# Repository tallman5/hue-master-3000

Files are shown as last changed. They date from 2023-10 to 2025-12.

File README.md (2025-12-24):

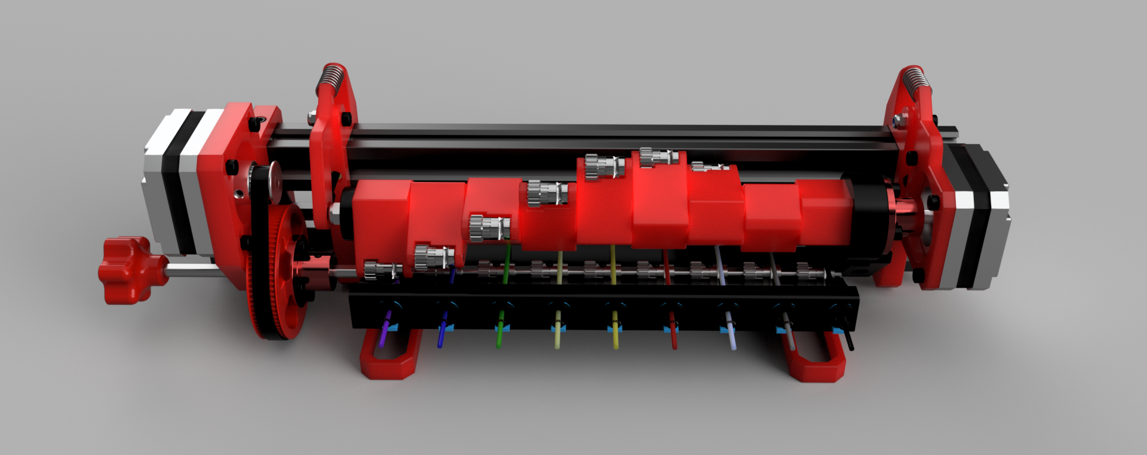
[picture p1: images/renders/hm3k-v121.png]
Hue Master 3000


# Hue Master 3000
The HM3K is a custom designed and built 3D printing MMU.

> [!WARNING]
> This project is still in Alpha phase. Use files at your own risk!

Watch the demo (https://youtu.be/Q2AsmqYf1VI)

BOM: [HM3K BOM](hm3k-bom.md)

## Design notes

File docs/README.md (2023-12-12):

# Assembly Instructions

## Printing the Parts
> [!WARNING]
> Failure to print the tests and callibrate the printer can lead to issues during assembly.

Before printing all the parts, print the test parts in the `../stl/test-prints` folder.
It's extremly important to ensure the printed parts fit together properly.
If they do not, the extrusion multiplier is probably what needs to be modified.

For reference, HM3K was built and tested with the following:
1. Print settings: Voron settings found in the [Voron Sourcing Guide](https://docs.vorondesign.com/sourcing.html) for all parts. The `feeder-block-9.stl` was printed with the infill dropped to 18%
1. Print profiles: Based on [AndrewEllis93's Profiles](https://github.com/AndrewEllis93/Ellis-SuperSlicer-Profiles)
1. Printer Tuning: [AndrewEllis93's Tuning Guide](https://ellis3dp.com/Print-Tuning-Guide/)

The two parts in the Voron Thread Test should screw together easily, not much force.
Once screwed together, there shouldn't be any wobble.

The HM3K test is a simple part which has holes for most of the critical joints used during assembly.
It has:
1. A tight hole in the side for a 6x3 mm magnet
1. A loose hole in the side for a 6x3 mm magnet
1. A hole down the center for testing the PTFE collet, clip, tube and filament
1. A hole to test a 5mm nut, should be snug but not difficult to instert the nut

## Next Step
1. Push extrusions through motor mounts, both directions

The HM3K is divided into two main assemblies, the Feeder (bottom) and the Selector (top).
They are joined with the two spine parts.

Next Step: [Feeder Assembly](./feeder-assembly.md)

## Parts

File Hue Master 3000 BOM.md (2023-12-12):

# Hue Master 3000 BOM
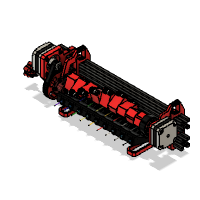
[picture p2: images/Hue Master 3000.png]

|Image|Name|Number|Description|Quantity|
|-|-|-|-|-|
||2020 V-Slot 300mm v2:1|2020 V-Slot 300mm||2|
||2GT 6mm Belt 5mm Shaft v3:1|HW1654WC|Affiliate Link: https://amzn.to/3tqusuo|1|
||Bearing MR85ZZ 5x8x2.5 v4:1|Bearing MR85ZZ 5x8x2.5|Affiliate Link: https://amzn.to/3LHrXdJ|1|
||Bowden Clip v5:1|Bowden Clip|Affiliate Link: https://amzn.to/3LXpI5Z|9|
||Bowden Collet v6:1|Bowden Collet|Affiliate Link: https://amzn.to/3LXpI5Z|9|
||Carrot Feeder Knob v2:1|Carrot Feeder Knob|Printed Part|1|
||Feeder Block v57:1|Feeder Block|Printed Part|1|
||Feeder Stepper Mount v34:1|Feeder Stepper Mount|Printed Part|1|
||Filament Gear Driven Assembly v5:1|Filament Gear Driven Assembly|Affiliate Link: https://amzn.to/3ZD1MdW|9|
||Filament Gear Idler Assembly v2:1|Filament Gear Idler Assembly|Affiliate Link: https://amzn.to/3ZD1MdW|9|
||Flange Coupling 5mm Assembly v4:1|Flange Coupling 5mm Assembly|Affiliate Link: https://amzn.to/46wvvrd|2|
||Foot v8:1|Foot||2|
||GT2 80T Wheel v8:1|GT2 80T Wheel|Printed Part|1|
||GT2 Belt 6x188 mm v2:1|GT2 Belt 6x188 mm|Affiliate Link: https://amzn.to/48znyTP|1|
||Hinged Spine v7:1|Hinged Spine||2|
||M3 Hex Lock Nut v1:1|HW1251NC||2|
||M3 T-Nut 2020 v2:1|HW1665NC|Affiliate Link: https://amzn.to/3RQrWbh|18|
||M3x10 SHCS v4:2|M3x10 SHCS|Affiliate Link: https://amzn.to/45f6QX4|9|
||M3x12 SHCS v3:1|M3x12 SHCS|Affiliate Link: https://amzn.to/3RQOZCR|2|
||M3x20 SHCS v2:1|M3x20 SHCS||1|
||M3x5x4 Threaded Insert v3:7|M3x5x4 Threaded Insert|Affiliate Link: https://amzn.to/48DnORF|10|
||M3x8 SHCS v3:1|M3x8 SHCS|Affiliate Link: https://amzn.to/3thA1vh|26|
||M5 D Shaft 269mm v3:1|M5 D Shaft 269mm||1|
||M5 Hex Lock Nut v2:1|HW1039NC|Affiliate Link: https://amzn.to/3RCXtxg|1|
||M5 Hex Nut v4:1|M5 Hex Nut||2|
||M5 Rod Threaded 205mm v1:1|M5 Rod Threaded 205mm||1|
||M5 Washer v3:2|M5 Washer|Affiliate Link: https://amzn.to/46Cpbyv|3|
||NEMA17 Square Short v5:1|NEMA17 Square Short|Affiliate Link: https://amzn.to/48Glbyz|2|
||Selector Arm v21:1|Selector Arm|Printed Part|9|
||Selector Axle End v12:1|Selector Axle End|Printed Part|1|
||Selector End Stop v15:1|Selector End Stop|Printed Part|1|
||Selector Flange Mount v26:1|Selector Flange Mount|Printed Part|1|
||Shaft Arm v13:1|Shaft Arm|Printed Part|1|
||Spring 20x8 Compressed v2:1|Spring 20x8 Compressed||2|
||Stepper Arm v12:1|Stepper Arm|Printed Part|1|

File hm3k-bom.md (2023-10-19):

# HM3K BOM


> [!WARNING]  
> This project is still in Alpha phase and the BOM is not complete. Use files at your own risk!

|Image|Name|Number|Description|Quantity|
|-|-|-|-|-|
||2020 V-Slot 260mm v1:1|2020 V-Slot 260mm||1|
||2020 x 250mm v1:1|2020 x 250mm||1|
||2GT 6mm Belt 5mm Shaft v3:1|HW1654WC|Affiliate Link: https://amzn.to/3tqusuo|1|
||Bearing MR85ZZ 5x8x2.5 v4:1|Bearing MR85ZZ 5x8x2.5|Affiliate Link: https://amzn.to/3LHrXdJ|2|
||Bowden Clip v5:1|Bowden Clip|Affiliate Link: https://amzn.to/3LXpI5Z|9|
||Bowden Collet v6:1|Bowden Collet|Affiliate Link: https://amzn.to/3LXpI5Z|9|
||Carrot Feeder Knob v2:1|Carrot Feeder Knob|Printed Part|1|
||Feeder Block v38:1|Feeder Block|Printed Part|9|
||Feeder Stepper Mount v20:1|Feeder Stepper Mount|Printed Part|1|
||Filament Gear Driven Assembly v5:1|Filament Gear Driven Assembly|Affiliate Link: https://amzn.to/3ZD1MdW|9|
||Filament Gear Idler Assembly v2:1|Filament Gear Idler Assembly|Affiliate Link: https://amzn.to/3ZD1MdW|9|
||Flange Coupling 5mm Assembly v4:1|Flange Coupling 5mm Assembly|Affiliate Link: https://amzn.to/46wvvrd|2|
||GT2 80T Wheel v8:1|GT2 80T Wheel|Printed Part|1|
||GT2 Belt 6x188 mm v2:1|GT2 Belt 6x188 mm|Affiliate Link: https://amzn.to/48znyTP|1|
||M3 T-Nut 2020 v2:1|HW1665NC|Affiliate Link: https://amzn.to/3RQrWbh|27|
||M3x10 SHCS v4:2|M3x10 SHCS|Affiliate Link: https://amzn.to/45f6QX4|9|
||M3x12 SHCS v3:1|M3x12 SHCS|Affiliate Link: https://amzn.to/3RQOZCR|9|
||M3x5x4 Threaded Insert v3:7|M3x5x4 Threaded Insert|Affiliate Link: https://amzn.to/48DnORF|8|
||M3x8 SHCS v3:1|M3x8 SHCS|Affiliate Link: https://amzn.to/3thA1vh|25|
||M5 D Shaft 269mm v3:1|M5 D Shaft 269mm||1|
||M5 Hex Lock Nut v2:1|HW1039NC|Affiliate Link: https://amzn.to/3RCXtxg|1|
||M5 Hex Nut v4:1|M5 Hex Nut||2|
||M5 Rod Threaded 205mm v1:1|M5 Rod Threaded 205mm||1|
||M5 Washer v3:2|M5 Washer|Affiliate Link: https://amzn.to/46Cpbyv|3|
||NEMA17 Square Short v5:1|NEMA17 Square Short|Affiliate Link: https://amzn.to/48Glbyz|2|
||Selector Arm v21:1|Selector Arm|Printed Part|9|
||Selector Axle End v12:1|Selector Axle End|Printed Part|1|
||Selector End Stop v10:1|Selector End Stop|Printed Part|1|
||Selector Flange Mount v26:1|Selector Flange Mount|Printed Part|1|
||Selector Motor Mount v18:1|Selector Motor Mount|Printed Part|1|
||Selector Shaft Mount v9:1|Selector Shaft Mount|Printed Part|1|
||Spine v6:1|Spine||2|

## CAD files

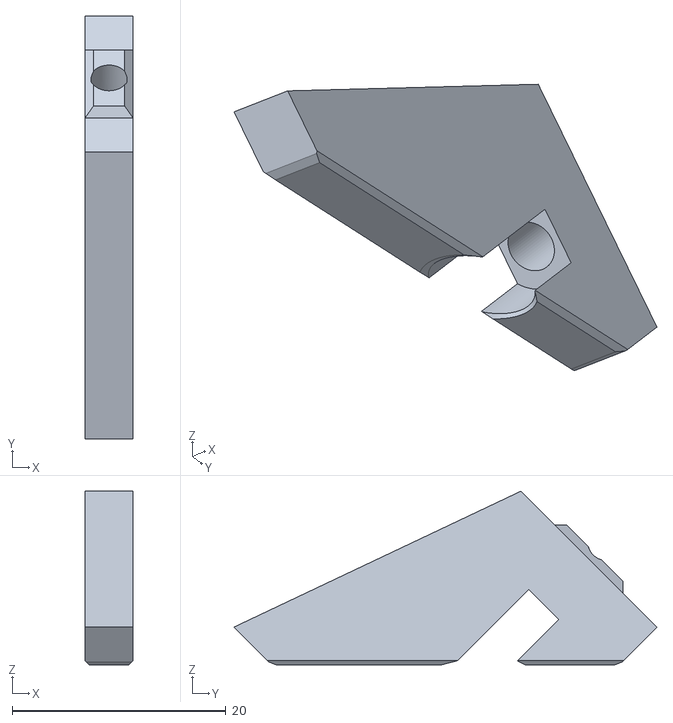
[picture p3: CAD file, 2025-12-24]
stl/ext-v-slot/selector-end-stop.stl
4.51 x 39.6 x 16.3

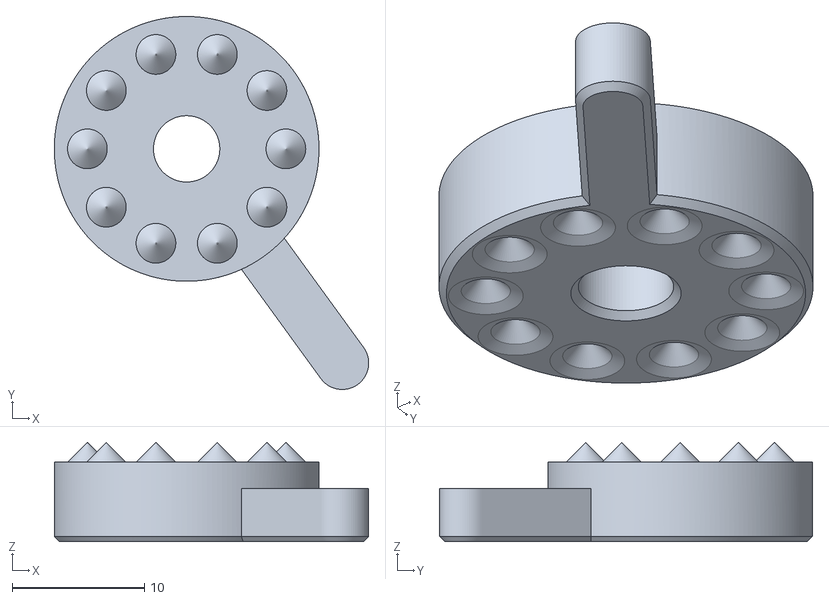
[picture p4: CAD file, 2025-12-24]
stl/selector-stop-arm.stl
23.8 x 28.2 x 7.50

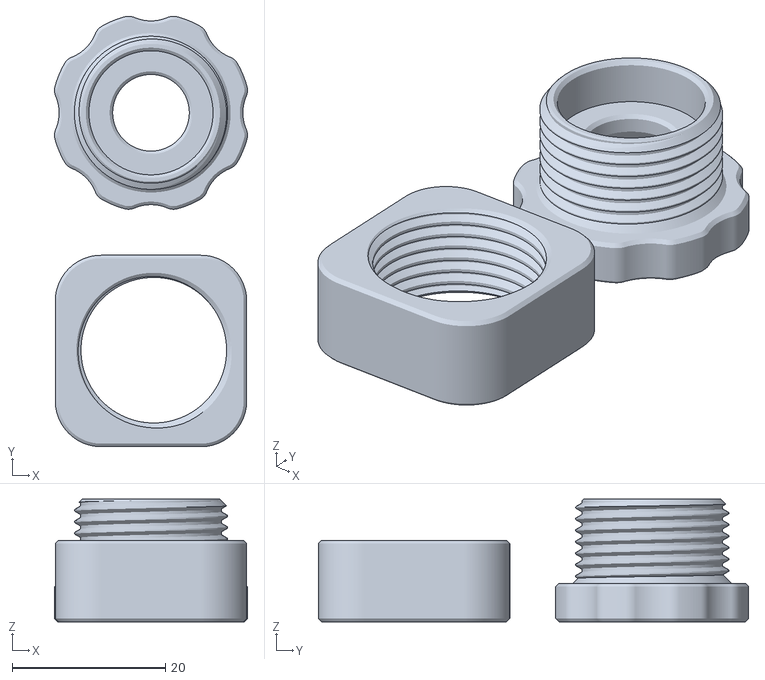
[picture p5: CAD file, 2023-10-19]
stl/test-prints/voron-thread-test.STL
25.2 x 56.2 x 16.0

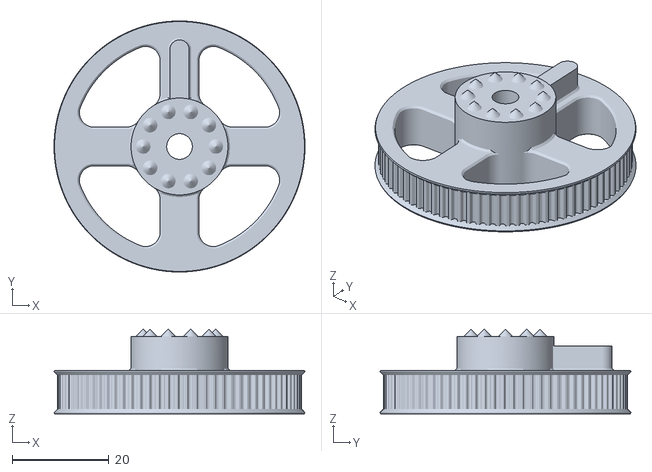
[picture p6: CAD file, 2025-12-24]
stl/[a]-selector-wheel.stl
51.8 x 51.8 x 17.5

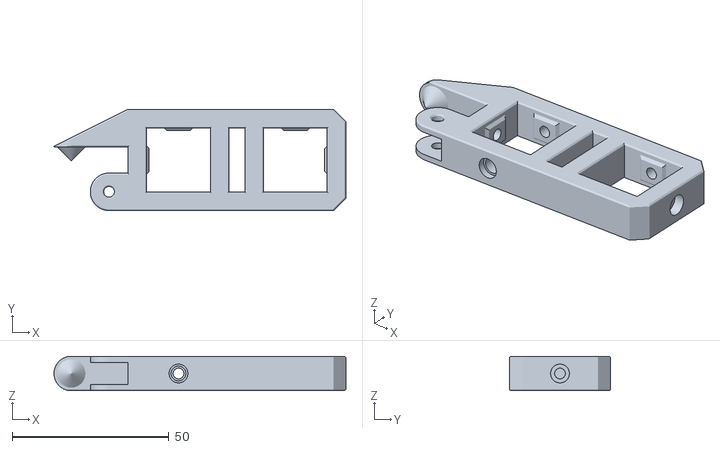
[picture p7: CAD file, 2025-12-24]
stl/ext-v-slot/hinged-spine-x2.stl
93.2 x 32.3 x 11.0

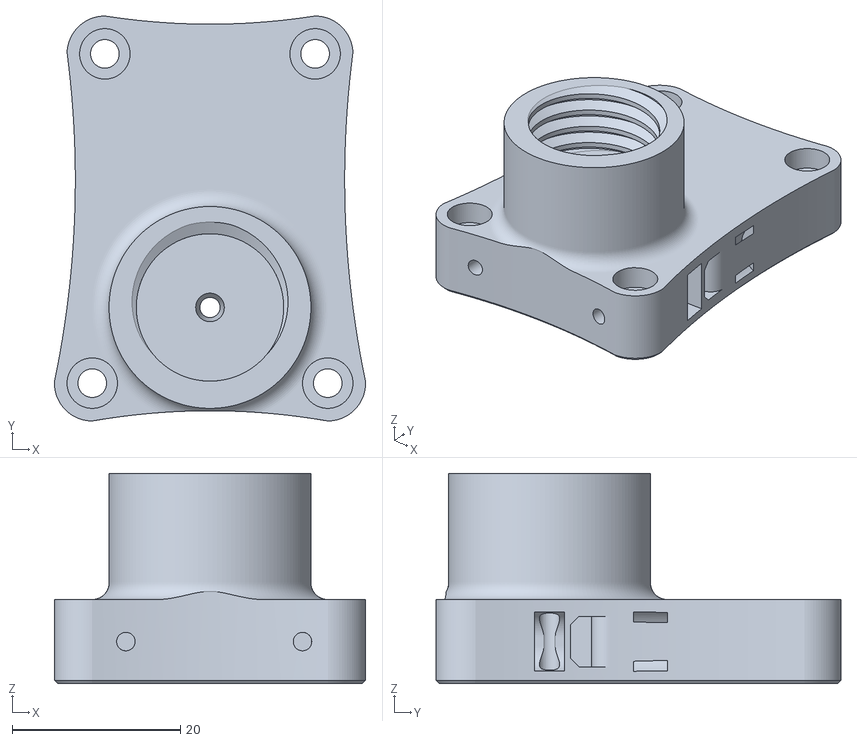
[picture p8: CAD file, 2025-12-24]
stl/ebm-mount.stl
37.0 x 48.2 x 25.0

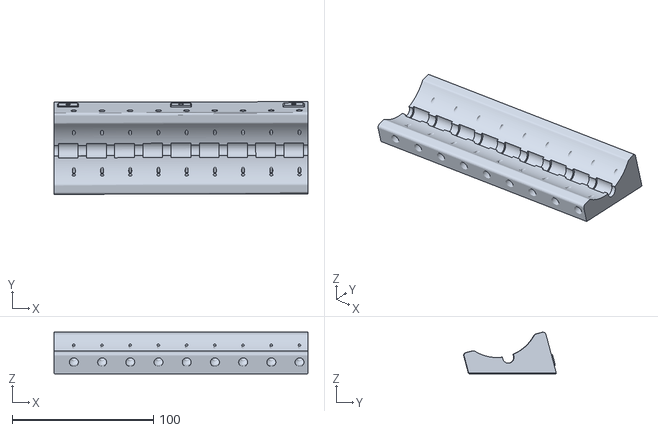
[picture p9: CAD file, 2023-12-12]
stl/ext-v-slot/feeder-block.stl
180.1 x 65.7 x 29.5

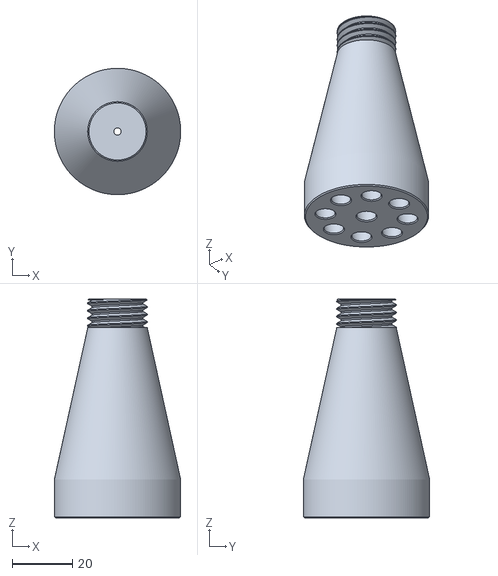
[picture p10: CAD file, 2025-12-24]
stl/bowden-merger.stl
42.0 x 42.0 x 72.8

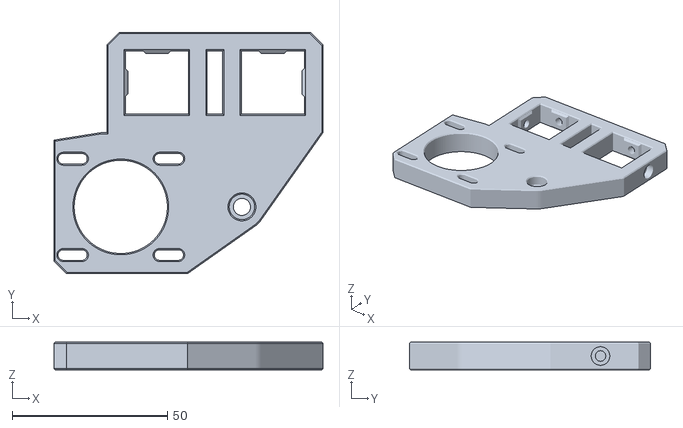
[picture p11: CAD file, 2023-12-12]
stl/ext-v-slot/[a]-feeder-stepper-mount.stl
86.6 x 77.7 x 9.00

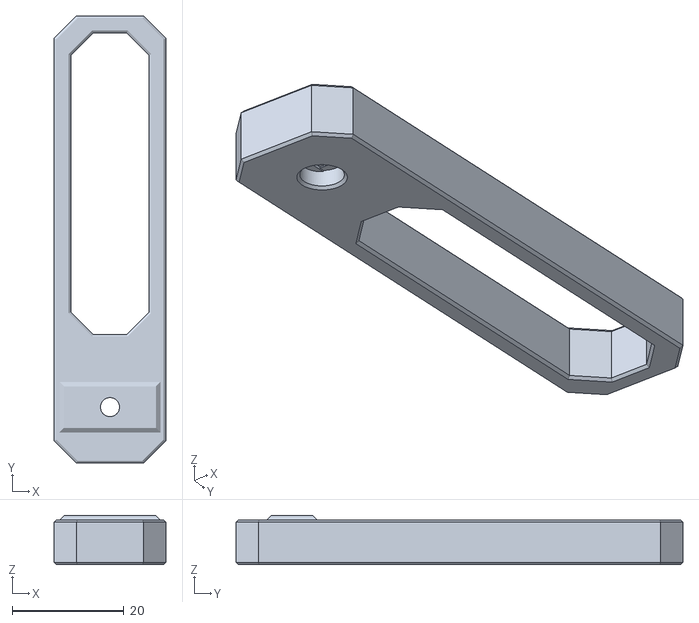
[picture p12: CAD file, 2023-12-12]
stl/ext-v-slot/[a]-foot-x2.stl
20.0 x 80.0 x 8.80

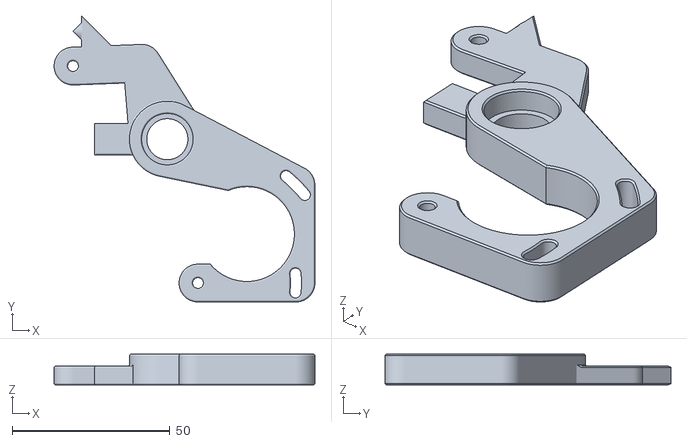
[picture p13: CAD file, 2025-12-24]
stl/stepper-hinge-arm.stl
82.6 x 90.5 x 9.80

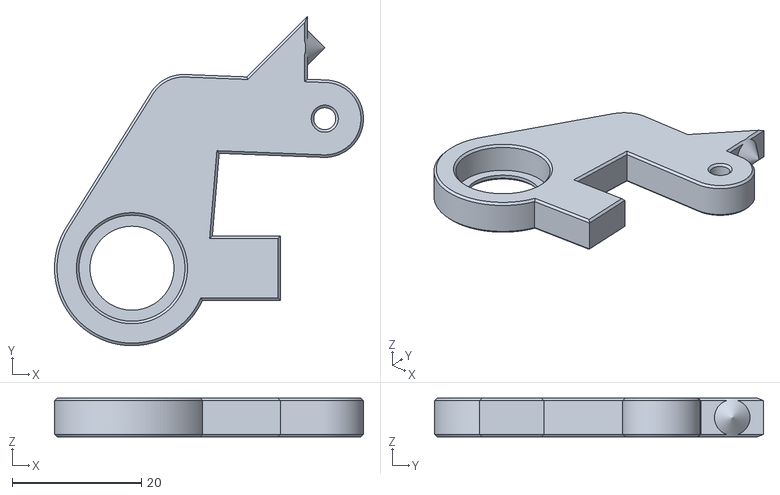
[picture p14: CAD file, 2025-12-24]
stl/shaft-arm.stl
47.8 x 51.0 x 6.00

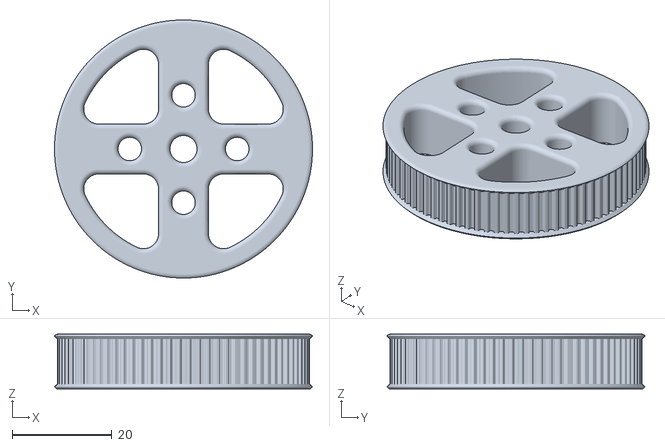
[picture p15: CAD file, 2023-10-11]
stl/[a]-gt2-80t-wheel.stl
51.6 x 51.6 x 11.0

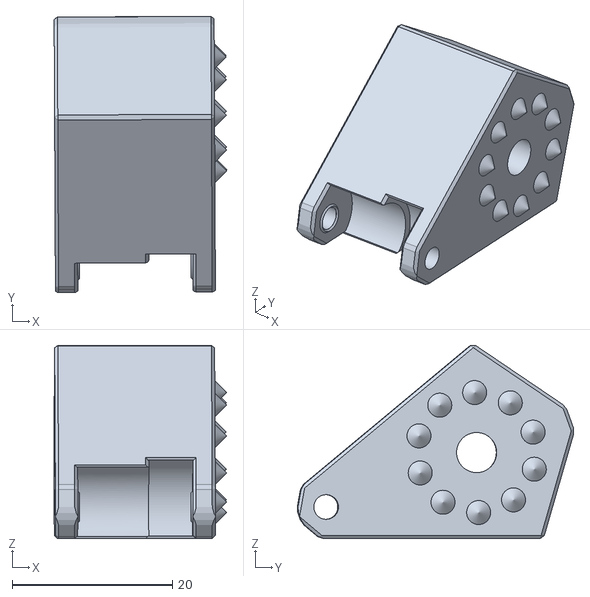
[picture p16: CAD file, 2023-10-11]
stl/[a]-selector-arm-x9.stl
21.6 x 34.5 x 24.1

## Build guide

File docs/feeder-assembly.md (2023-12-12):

# The Feeder
1. Add bearing to the feeder stepper mount
1. Add M3x8s and nuts
1. Mount 2GT on stepper
1. Loosly mount stepper to feeder stepper mount
1. Slide mount on end of extrusion, flush with end, do not tighten
1. Add 80T to flange
1. 80T/Flange/Washer on D Shaft
1. Gears and bearings on D Shaft
1. Knob/Belt on D Shaft
1. Slide stepper up and tighten
1. Add feet
1. Slide on 12mm (15mm?) spacer
1. Screws and nuts on feeder blocks
1. Feeder block on extrusion, align to first gear
1. Move gears to spaces, make sure spin freely
1. Tighten blocks to extrusion
1. Use filament to align geers

## Next Steps

Next Step: [Selector Assembly](./selector-assembly.md)
<br/>Previous Step: [Assembly Instructions](./README.md)

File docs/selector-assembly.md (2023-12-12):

# The Selector
1. Add the idler filament gear (not the one with the set screw), bearings and shaft to the selector arm.
   Repeat for the other eight arms.
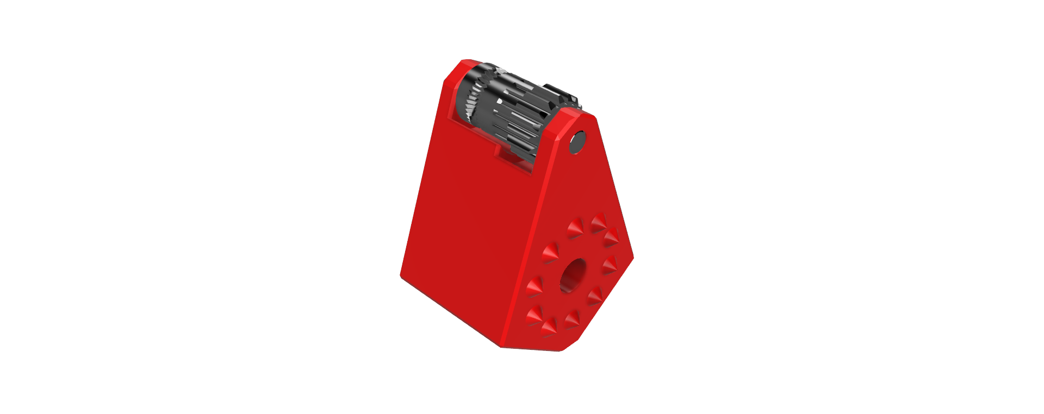
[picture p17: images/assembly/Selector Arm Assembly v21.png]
   <br />
1. Thread a nut, washer and nut on one end of the threadded rod. Keep the end nut as close to the end of the rod as possible. Crank down on the nuts so they will not slip when running.
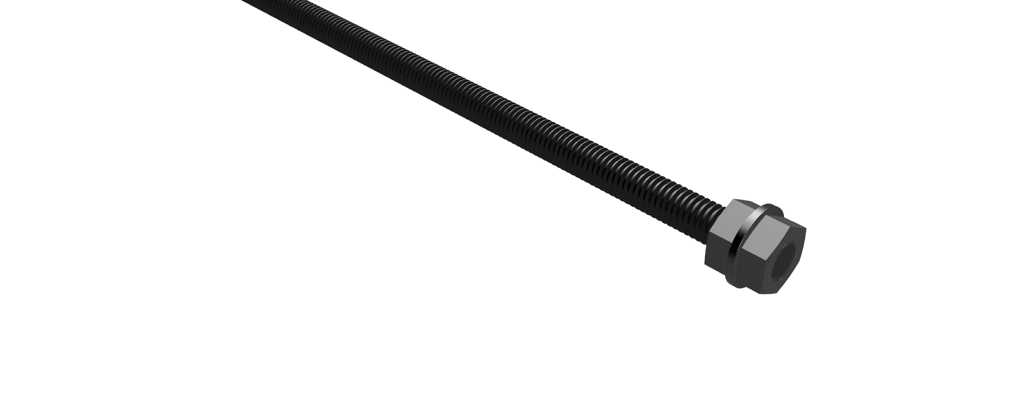
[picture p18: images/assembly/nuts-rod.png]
   <br />
1. Add four threaded inserts to the flange mount.
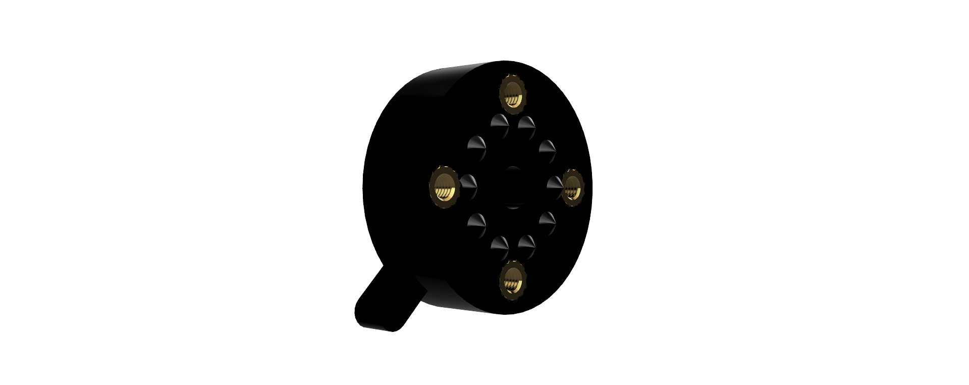
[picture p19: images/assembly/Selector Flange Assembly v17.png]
   <br />
1. Push the rod through the flange mount. Ensure the end nut is at least flush with the face of the mount.
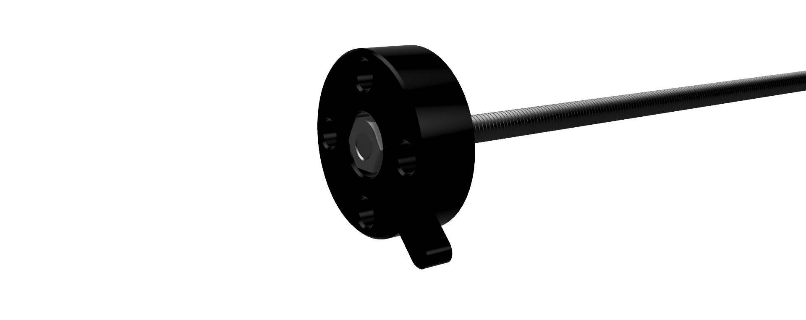
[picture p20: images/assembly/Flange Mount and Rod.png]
   <br />
1. Screw the coupling to the mount using four M3x10 screws.
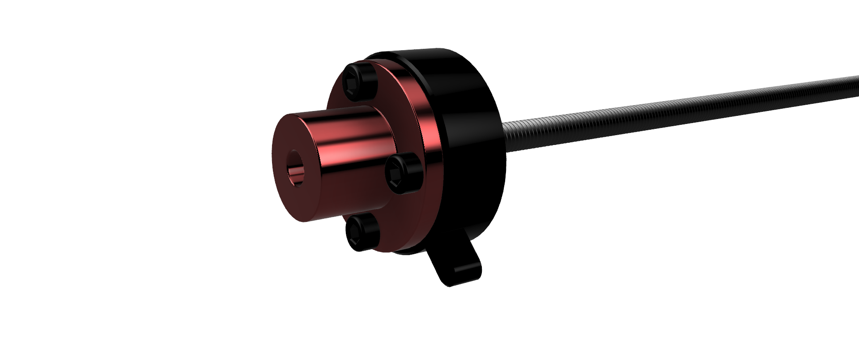
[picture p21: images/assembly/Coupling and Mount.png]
   <br />
1. Screw stepper to stepper mount
1. Add screws and nuts to stepper mount
1. Slide on extrusion, flust with end
1. Slide on shaft support

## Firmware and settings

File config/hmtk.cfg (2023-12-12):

[gcode_macro HMTK_VARS]
description: Echo HMTK variables to the console.
variable_channel_positions = [4.5, 8.5, 12.5, 16.5, 20.5, 24.5, 28.5, 32.5, 36.5]
variable_current_channel: -1
variable_is_homed: False
gcode:
  ECHO_HMTK_VARS

[gcode_macro ECHO_HMTK_VARS]
description: Echo HMTK variables to the console.
gcode:
  {% for var, value in printer["gcode_macro HMTK_VARS"].items() %}
    {action_respond_info(var ~ ": " ~ value)}
  {% endfor %}

[tmc2209 manual_stepper selector_stepper]
diag_pin: ^PG12
driver_sgthrs: 40
interpolate: false
run_current: 0.7
sense_resistor: 0.110
stealthchop_threshold: 0
uart_pin: PF2

[manual_stepper selector_stepper]
accel: 1000
dir_pin: !PF10
enable_pin: !PG2
endstop_pin: tmc2209_selector_stepper:virtual_endstop
full_steps_per_rotation: 200
microsteps: 32
rotation_distance: 40
step_pin: PF9
velocity: 20

# [tmc2209 manual_stepper selector_stepper]
# diag_pin: ^PG12
# driver_sgthrs: 240
# # hold_current: 0.2
# interpolate: True
# run_current: 0.4
# sense_resistor: 0.110
# stealthchop_threshold: 100
# uart_pin: PC7

# [manual_stepper selector_stepper]
# accel: 1000
# dir_pin: !PC1
# enable_pin: !PA0
# endstop_pin: tmc2209_selector_stepper:virtual_endstop
# full_steps_per_rotation: 200
# microsteps: 32
# rotation_distance:  40
# step_pin: PG4
# velocity: 200

# [tmc2209 manual_stepper feeder_stepper]
# hold_current: 0.4
# interpolate: true
# run_current: 0.8
# stealthchop_threshold: 0
# uart_pin: PF2

# [manual_stepper feeder_stepper]
# accel: 1000
# dir_pin: !PF10
# full_steps_per_rotation: 400
# enable_pin: !PG2
# microsteps: 64
# rotation_distance:  16.808
# step_pin: PF9

[gcode_macro _ANNOUNCE]
description: Sends a message to the terminal and the screen
gcode:
  M117 {params.MSG}
  RESPOND MSG="{params.MSG}" PREFIX=""

[gcode_macro _HOME_HMTK]
description: Homes the HMTK
gcode:
  _ANNOUNCE MSG="Homing HMTK Selector..."
  MANUAL_STEPPER STEPPER=selector_stepper SET_POSITION=40
  MANUAL_STEPPER STEPPER=selector_stepper MOVE=0 STOP_ON_ENDSTOP=1
  MANUAL_STEPPER STEPPER=selector_stepper SET_POSITION=0
  SET_GCODE_VARIABLE MACRO=HMTK_VARS VARIABLE=is_homed VALUE=True
  SET_GCODE_VARIABLE MACRO=HMTK_VARS VARIABLE=current_channel VALUE=-1
  _ANNOUNCE MSG="Done homing HMTK"

[gcode_macro _HOME_HMTK_IF_NEEDED]
description: If the HMTK isn't homed, home the selector
gcode:
  {% if printer["gcode_macro HMTK_VARS"].is_homed|lower == 'false' %}
    _HOME_HMTK
  {% endif %}


[gcode_macro _HMTK_CHANGE_TOOL]
description: Change to the desired tool
gcode:
  _ANNOUNCE MSG="Changing tool..."
  _HOME_HMTK_IF_NEEDED
  MANUAL_STEPPER STEPPER=selector_stepper MOVE={printer["gcode_macro HMTK_VARS"].channel_positions[params.TOOL|int]}
  
[gcode_macro T0]
description: Change to tool 0
gcode:
  _HMTK_CHANGE_TOOL TOOL=0

[gcode_macro T1]
description: Change to tool 1
gcode:
  _HMTK_CHANGE_TOOL TOOL=1

[gcode_macro T2]
description: Change to tool 2
gcode:
  _HMTK_CHANGE_TOOL TOOL=2

[gcode_macro T3]
description: Change to tool 3
gcode:
  _HMTK_CHANGE_TOOL TOOL=3

[gcode_macro T4]
description: Change to tool 4
gcode:
  _HMTK_CHANGE_TOOL TOOL=4

[gcode_macro T5]
description: Change to tool 5
gcode:
  _HMTK_CHANGE_TOOL TOOL=5

[gcode_macro T6]
description: Change to tool 6
gcode:
  _HMTK_CHANGE_TOOL TOOL=6

[gcode_macro T7]
description: Change to tool 7
gcode:
  _HMTK_CHANGE_TOOL TOOL=7

[gcode_macro T8]
description: Change to tool 8
gcode:
  _HMTK_CHANGE_TOOL TOOL=8

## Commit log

2023-10-11 incomplete bom
    [[a]-gt2-80t-wheel.stl, [a]-idler-arm-x9.stl, axle-end.stl]
2023-10-19 updating frame
    [[a]-selector-arm-x9.stl, [a]-spine-x2.stl, axle-end.stl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]
2023-12-12 updating a lot
    [[a]-feeder-stepper-mount.stl, [a]-foot-x2.stl, [a]-hinged-spine-x2.stl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]
2025-12-24 updating reame
    [[a]-hinged-spine-x2.stl, [a]-selector-wheel.stl, [a]-shaft-arm.stl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]
